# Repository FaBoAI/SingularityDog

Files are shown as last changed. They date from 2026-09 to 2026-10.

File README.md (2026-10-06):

# SingularityDog

**GPT-6 Astraが、3D CADの設計・強化学習・評価・改善を進めるロボット犬プロジェクト。**

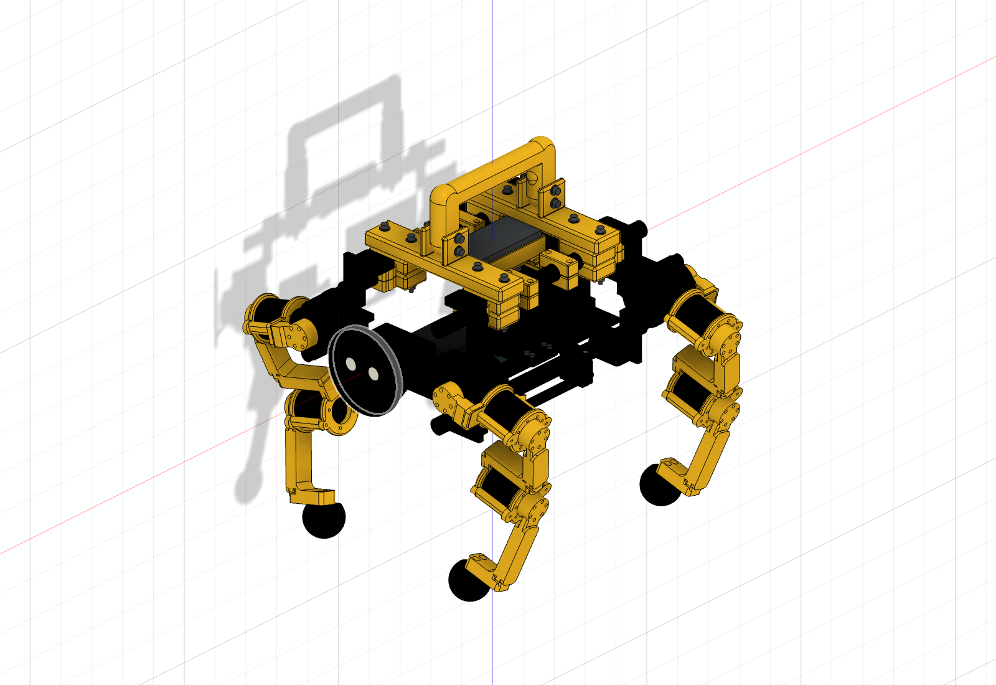
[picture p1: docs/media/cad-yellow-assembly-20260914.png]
SingularityDogの黄色・黒のCAD全体像。黄色の脚・取手、黒いBodyと顔を備えた2026年9月14日の全体CAD更新版


*黄色の脚・取手と黒いBody・顔を反映したCAD全体像（2026-09-14の全体更新版）。その後の共通底板・顔固定・左右連結部・足先の改訂は、[最新STL部材一覧](docs/stl-parts.md)で確認できます。*

**[BOM・部品表](docs/bom.md)** · **[色別STL・ダウンロード](docs/stl-parts.md)** · [動画で見る進捗](#動画で見る進捗) · [実機向けソフトウェア開発](#実機向けソフトウェア開発) · [実機Deploy](#実機deployの状況) · [現在の課題](#現在の課題) · [ハードウェアライセンス](#ハードウェアライセンス)

## GPT-6 Astraと、実物を作りながら開発する

SingularityDogは、**GPT-6 Astraを開発エージェントに据え、人と一緒にロボット犬を作る**FaBoのプロジェクトです。GPT-6 Astraが機構・固定具の設計変更、STLの準備、制御・学習コード、Isaac Labでの実験と結果整理を進めます。人は目標を決め、部品の採寸・調達・印刷・組立を行い、割れや嵌合などの現物情報を返します。

**設計 → シミュレーション・学習 → 動画と数値で評価 → 印刷・現物合わせ → 実機計測 → 改善**を繰り返します。うまくいかなかった試行も記録し、次の設計と学習に反映する開発記録です。

シミュレーションは**第37回まで評価済み**です。実機ではRS05全12軸を公式FW 0.5.0.13へ更新し、前後2系統のCANで保持・停止を確認しています。前進の最終目標は40cm/sです。

## 実機向けソフトウェア開発

**[10月6日の総括・残件の○△×表](docs/work-summary-20261006.md)**。C複製＋FK最適化で無出力の定常1,000周期を20ms以内に収めました。新設定の実Type1出力、荷重支持、自立、歩行は残件です。今日の修正ソース・テスト・IMU候補・実出力の先行履歴をまとめています。

**[10月6日夜：20ms超過の原因調査と修正](docs/20ms-cause-investigation-20261006.md)**。**0.90ms送信間隔・20ms制御周期を維持し、無出力の定常1,000周期を20ms以内に収めました。** C++待機の修正、関節目標のC++化＋FK再利用、snapshotのC複製を組み合わせたr49で、取得・実推論・12軸STOP代理返信・後処理を500周期×2回測定。最大19.856942／19.788521ms、定常超過・周期スキップ0で、原通信と設定復元も独立確認しました。初回20.066911／20.045173msは許容された初回として別記録。出力98値の新C++変換も保存入力で短縮を確認しましたが、今回の周期には未統合です。**新設定の実Type1出力・荷重・立位・歩行は残件**です。[本日の記録とToDo](docs/today-validation-20261006.md)・[実出力の履歴](docs/corrected-output-validation-20261006.md)。

**[10月5日の総括・残件の○△×表](docs/work-summary-20261005.md)**。静止速度・原点精度の解析、校正入力と保存処理の修正、気泡式水準器1台用の簡単な音声手順r2も含めて整理しました。ID4・5・10の相対方向候補は確認済み、絶対原点とIMUの正式校正、現設定の学習目標実送信・荷重立位・歩行は残件です。

**2026年10月5日：gyro偏差を選択したr3の無出力実モデル診断で、定常500周期を2回とも20ms以内に収めました。** 最大19.355386ms／19.253048ms・処理時間超過0・返信欠落0。gyro候補は未承認の仮定として入力へ適用し、加速度はrawのままです。開始間隔最大20.073992ms／20.005319msの厳密20ms未達と、短い5周期の初回20.014758msも残します。一括静止比較は速度判定でBLOCKED、全12軸の最終原点・IMU絶対校正は未確定、新設定の学習目標送信・荷重立位・歩行は未実施です。[今日の記録・手順](docs/today-validation-20261005.md)・[r1〜r3実測集計](evidence/validation-live-timing-20261005.json)。今週10月5〜11日に、正式荷重設定→部分荷重→自立→短距離歩行を目指します。[修正・○△×表・日別計画](docs/walking-week-20261005.md)。`r`／`R`番号は各ツール・試験内の改訂番号で、学習評価回数とは別です。

| 日付（2026年） | 版・作業記録 | 成果・状況 |
|---|---|---|
| 9月20日 | [診断 r2・r4](docs/hardware-bringup-20260920.md) | 12軸の位置・速度・電流・電圧とIMUを取得。60秒診断でCANタイムアウト0回。 |
| 9月21日 | [関節試験・推論環境](docs/hardware-results-20260921.md) | 支持台上で右前脚の動作・停止を確認。12軸の逐次取得は中央値81.20ms。 |
| 9月22日 | [FW照会・校正準備](docs/hardware-results-20260922.md) | 全12台の版数を照会し、設定読取り失敗を切り分け。試験前の設定確認を一括化。 |
| 9月23日 | [前後2系統CAN・交換後の試験](docs/hardware-results-20260923.md) | USB2CANを前脚・後脚に分割。交換後の脚別動作・停止と4脚のL字基準を記録。 |
| 9月24日 | [保持 r1〜r6](docs/hardware-results-20260924.md)・[20ms化の方針](docs/control-20ms-strategy-20260924.md) | 右後脚の追従とゲインを比較。位置・速度の複合返信、並列取得・送信の改善方針を整理。 |
| 9月25日 | [FW更新・実機結果](docs/2026-09-25-26-hardware-status.md#9月25日)・[C++化 r10／r8](docs/hardware-native-host-processing-20260925.md) | 全12軸をFW 0.5.0.13へ更新。取得→実推論→最終ホスト送信は3回中最良19.785ms、最大20.136ms。連続20msは未達。 |
| 9月26日 | [音声案内・12軸保持](docs/2026-09-25-26-hardware-status.md#9月26日)・[4軸同時試験](docs/role-thigh-mirrored-20260926.md) | 「テスト開始します」の発話と12軸保持・STOPを確認。前脚付け根の10°軌道は未完了。 |
| 9月27日 | [並列取得・無出力推論 r3・r4](docs/learned-policy-deploy-status-20260927.md) | 前後CAN・IMUを並列化し、単発の実推論に成功。r4はCAN取得中央値22.183msで、20ms未達。 |
| 9月27日夜 | [翌日の一括検証キット](docs/overnight-validation-20260927.md) | 360°ずれの補正、IMU校正、C++送受信・推論を統合。保存通信492件の一致と模擬20周期を確認。 |
| 9月28日 | [速度改善 r6〜r13](docs/hardware-native-cycle-20260928.md) | 複合返信、スレッド事前起動、コピー削減、ログ後処理化。r13は無出力500周期の全工程最大21.640ms、16回超過。 |
| 9月28日 | [CPU・推論比較 r14〜r17・R20〜R22](docs/latency-alternatives-20260928.md) | Super Modeと推論の準備手順を改善。**R22で無出力500周期すべて20ms以内（全工程最大19.695ms）を達成。** |
| 9月28日 | [実出力 V2／V3](docs/policy-output-validation-20260928.md)・[立位〜低速歩行ツール](docs/ground-trials-20260928.md) | 滑らかな開始・停止、C++送受信、関節監視を実装。V3は周期内の要求を28→26へ削減。 |
| 9月28日夜 | [角度・IMU照合、指令断確認 r4](docs/walking-residuals-20260929.md)・[40V再投入5回](docs/power-cycle-repeat-20260928.md) | 水準器で4脚L字とIMU水平を記録。ゼロゲインの指令断保護・終了STOPを12軸で確認。加速度ノルム約9%の偏差は残る。 |
| 9月28日夜 | [⑤ 最終入力の無出力診断](evidence/final-input-diagnostic-20260928.json) | **取得→実推論→STOP返信・後処理まで、初回1＋定常500周期すべて20ms以内を達成。全工程最大19.555ms、超過0回。** |
| 9月29日未明 | [⑥ 箱支持の実出力試行](evidence/supported-policy-attempt-20260928.json) | 開始保持2周期後、指令計算間隔の上限で中断。学習目標は未送信。終了STOPは10軸確認・2軸未確認となり、40V Off・現物異常なしを確認。 |
| 9月29日未明 | [朝の再開手順・修正版](docs/morning-restart-20260929.md) | 指令間隔の記録とSTOP返信処理を修正し、CPU配置の比較設定を追加。**2,303件成功・5件スキップ**。修正版の実機再試験は未実施。 |
| 9月29日 | [実出力と20ms比較](docs/20ms-fast-voltage-benchmark-20260929.md)・[推論のC++候補](docs/20ms-model-hotpath-20260929.md) | 箱支持で学習目標を混ぜる2秒試験を95周期完走・全軸STOP。数値計算スレッドを起動時に制限した無駆動診断は、初回を除く**3回×500周期で20ms超過0回**（各回最大19.392／19.303／19.910ms）。同じCPU4で追加の定常500周期も最大19.663ms・超過0。新設定の実出力は初回ゼロゲイン周期で返信が欠け、学習目標送信前に中断。 |
| 9月29日 | [STOP再送と返信欠落の切り分け](docs/stop-retry-20260929.md) | ゼロゲインのType1比較は29周期完了後、30周期目のID4返信欠落で中断。40V Off・現物異常なし。STOP最大3回・合計500msの再送を実装し、実機での効果は未計測。 |
| 9月29日 | [STOP再送版の箱支持実出力 r1](evidence/supported-policy-stopretry-20260929.json) | 充電後、ゼロゲイン88周期と学習目標送信97周期を完走。学習目標側は全工程最大**19.575ms・20ms超過0回・全12軸STOP**。モデル混合率0.5%、最大1°の限定試験。再送は発動せず、返信欠落時の回復効果と長時間安定性は未確認。 |
| 9月29日 | [12cm支持・5秒試験 r1〜r6](docs/ground-support-rehearsal-20260929.md)・[集計](evidence/supported-policy-box120-20260929.json) | STOP初回250ms・再送最大500ms・合計1秒、有効化返信30ms、終了ランプの丸め誤差を修正。r6は32周期（学習目標12周期）後にID12返信欠落で中断。完了周期最大19.439ms。40V Off・現物異常なしを確認。5秒完走と通信欠落の解消は未達。 |
| 9月29日 | [CAN/USB欠落調査・skip試作](docs/can-usb-loss-investigation-20260929.md) | 返信全体の未着と末尾2バイトの遅着を分類。xHCIの受動監視ツールを追加。最大1周期の受信待ちを模擬検証し、Mac74件・JetsonのC++ socket3件成功。実出力のskipは未適用、欠落の物理的な発生箇所は未確定。 |
| 9月29日 | [実機Type17・USB双方向記録](docs/can-usb-loss-investigation-20260929.md)・[集計](evidence/can-usb-type17-live-20260929.json) | 箱支持・無指令で500周期を完走。xHCIは前後両CH341の送受信URBを損失なく記録。ID9の40V再投入後の約1回転枝差を診断用に照合。Type1欠落の発生箇所は未確定。 |
| 9月29日 | [ID9角度照合・推論＋STOP代理100周期](docs/can-usb-loss-investigation-20260929.md)・[集計](evidence/can-stopproxy-diagnostic-20260929-r3.json) | 現起動12軸の無出力読取りを診断用プロファイルと照合し、100周期を完走・全12軸STOP返信を確認。標準モデル経路では推論区間中央値28.729ms、全工程中央値46.191ms。高速C++モデルの指定漏れを防ぐCLIスイッチを追加し、同条件の再比較を準備。 |
| 9月29日 | [高速C++モデルの無出力再計測](docs/can-usb-loss-investigation-20260929.md)・[集計](evidence/can-stopproxy-fastscalar-20260929-r5.json) | CPU周波数を計測中だけ固定し自動復元。初回1＋定常500周期を完走し、定常の取得→実推論→12軸STOP返信・後処理は中央値18.831ms、最大19.482ms、20ms超過0回。Type1指令とモーター有効化はゼロ。実出力と厳密な開始間隔20ms以内は未確認。 |
| 9月29日 | [Type1欠落の密度・有効化比較](docs/can-usb-loss-investigation-20260929.md)・[集計](evidence/can-usb-loss-followup-20260929.json) | 実出力r7は43周期目のID4返信が欠落し、物理40V Off。脱力中の26要求r17は50周期、有効化ゼロゲインの同密度r19も50周期を完走し、いずれも全軸STOP。r19は前後各710要求／返信、USB送受信各12,070Bが一致。**欠落原因は未特定**で、長時間の学習目標出力は未承認。 |
| 9月29日 | [native通信密度比較 r20〜r29](docs/can-usb-loss-investigation-20260929.md)・[集計](evidence/can-usb-loss-followup-20260929.json) | CPU・待機最適化後の0.8msは50周期すべて20ms以内だが、500周期試行の19周期目で返信欠落。USB受信側でも17B不足を確認。**1.0ms間隔ではゼロゲイン500周期を欠落なし・全12軸STOPで完走**。最大20.415ms、20ms超過16周期。0.9msでは186周期完了・187周期目にID4速度0.506rad/sで停止、返信欠落・時間超過はなく最大19.427ms、全軸STOP。学習目標・荷重試験の成功ではない。 |
| 9月29日 | [新起動の静止読取り・返信比較 r30・r31](docs/stationary-readonly-check-20260929.md) | r30は全12軸・10秒・3012要求を完了し、角度幅最大0.02552°。r31は36 STOP返信すべてmode0・fault0、ID4・6は各3回一致。全体は31一致・5判定保留。有効化・学習目標送信なし。実出力、最終角度承認、20ms達成の判定には用いない。 |
| 9月29日 | [0.9msの推論・STOP診断 r33〜r36](docs/control-loop-gil-optimization-20260929.md) | Python切替100µsと電圧通信準備後の通知で、r36は初回20.175ms・定常500周期すべて20ms以内（最大19.940ms）、返信欠落なし。修正版の通信断保護も12軸合格。過去起動の実測として保存。充電後の現起動の結果は次行。 |
| 9月29日 | [満充電・STOP解析短縮 r38〜r43](docs/control-loop-gil-optimization-20260929.md) | 現電源の通信断保護は全12軸合格。r43は501周期返信欠落なし、定常499/500周期が20ms以内（中央値19.273ms）。残る1周期は返信後処理で21.100msとなり、支持付き実出力の開始条件は未達。学習目標は未送信。 |
| 9月29日 | [C++一括エンコード・支持付き実出力 r46〜r49](docs/control-loop-gil-optimization-20260929.md#c一括エンコードで支持付き実出力を完走r48r49)・[集計](evidence/control-loop-gil-20260929.json) | r48は入力年齢20.048msで中断・学習未送信・全軸STOP。C++一括エンコーダーを選んだr49は**2秒枠・92周期を正常終了し、全工程最大19.959ms・超過0回・全12軸STOP・現物異常なし**。学習混合48周期、上限0.5%・最大1°。開始間隔最大20.0226ms。10秒・荷重立位・歩行は未実施。 |
| 9月29日 | [10秒版の初回試行 r50](docs/control-loop-gil-optimization-20260929.md#10秒版の初回試行r50途中停止)・[集計](evidence/control-loop-gil-20260929.json) | 開始2周期が20.110677／20.062804msとなり、返信後の連続超過で中断。学習混合率0・学習目標未送信、全12軸STOP・現物異常なし。**10秒完走は未達**で、開始直後の処理を調査中。r49の2秒成功とは別に保存。 |
| 9月29日 | [初回猶予の2秒再確認 r51](docs/control-loop-gil-optimization-20260929.md#初回猶予を明示した2秒再確認r51鮮度で中断)・[集計](evidence/control-loop-gil-20260929.json) | 最初の周期が20.309195ms、入力年齢20.093303msで中断。鮮度条件を満たさず初回猶予は未使用。学習目標未送信、全12軸STOP・現物異常なし。開始処理・返信解析の短縮が残る。 |
| 9月29日 | [主制御の返信解析短縮・2秒再完走 r52・r53](docs/control-loop-gil-optimization-20260929.md#固定長返信解析で2秒を再完走r52r53)・[集計](evidence/control-loop-gil-20260929.json) | r52は54周期後に指令計算間隔21.364msで中断・全軸STOP。主制御解析を短縮したr53は**92周期正常終了、初回20.138msの猶予1回、定常最大19.887ms・超過0回、全12軸STOP・現物異常なし**。学習混合48周期・モデル68回。最大1°／混合0.5%の箱支持試験で、次は同じソースの10秒確認。 |
| 9月29日 | [同一ソースの10秒完走 r54](docs/control-loop-gil-optimization-20260929.md#同一ソースの10秒枠を完走r54)・[集計](evidence/control-loop-gil-20260929.json) | **494周期で正常終了、モデル468回・学習混合448周期・全12軸STOP・現物異常なし**。全工程中央値19.362ms、単発超過1回・最大20.190ms。最終返信は全周期20ms以内。最大1°／混合0.5%の箱支持試験。次は箱を残した荷重用保持の確認で、支持減・自立・歩行は未実施。 |
| 9月29日 | [箱支持Kp12・3秒保持 r55](docs/control-loop-gil-optimization-20260929.md#箱を残したkp12の3秒保持r55)・[集計](evidence/control-loop-gil-20260929.json) | **138周期で正常終了、全工程最大19.624ms・超過0回・全12軸STOP・現物異常なし**。Kp12/Kd0.15へ1秒かけて上げ、現在位置を保持。周期中のモデル呼出し・学習目標は0。箱を残した試験であり、荷重移行・自立・歩行の証明ではない。 |
| 9月29日 | [固定受け付き30秒保持の試行 r56f・r57](docs/fixed-catch-hold-20260929.md) | r56fは姿勢変更後の開始角不一致で駆動前停止。r57は高い箱を抜いた後、約6.1秒でIMU値により中断し全12軸STOP。実測トルクは最大約0.11 Nmで、脚の荷重支持は確認できなかった。次は箱を残して小変位の脚伸展と荷重を測る。 |
| 9月29日 | [学習目標0.5%→1%・Kp6の支持付き出力 r63・r64](docs/fixed-catch-hold-20260929.md#同日夜のkp6学習目標1段階試験)・[集計](evidence/supported-gain-contact-20260929.json) | r63は2秒枠・95周期、r64は3秒枠・143周期で正常終了。両方とも定常20ms超過0・全12軸STOP・現物異常なし。r64の最大実測トルク約0.065Nm、最大実移動約0.066°で、荷重支持の証明ではない。 |
| 9月29日 | [4足接触確認と0.25mm往復経路 r65](docs/fixed-catch-hold-20260929.md#紙による4足接地確認後の読取りr65) | 4足で紙が軽く挟まることを操作者が確認。12軸の静止角を無駆動で取得し、5秒往復経路を数値検査。微小IKの収束誤差を修正。専用実行処理への接続・異常時STOP検証・新電源での照合は残件で、実機への経路送信は未実施。 |
| 9月30日 | [5秒の伸展・復帰処理](docs/supported-preload-runtime-20260930.md)・[追加課題の修正](docs/additional-fixes-20260930.md)・[ToDoと時間](docs/walking-plan-20260930.md) | 専用実行モード、角度枝・復帰・STOPを実装。追加監査で古いSTOPの混入、終了・速度判定、旧診断の流用、送信角の量子化、キット一覧の重複を修正。Mac上の擬似通信で検証し、現電源での診断・実機送信・荷重移行は残件。 |
| 9月30日 | [全体監査・総合課題表](docs/system-readiness-20260930.md)・[モデル規模とESP32](docs/model-footprint-esp32-20260930.md) | 取消例外とSTOP結果保存、端末出力の詰まり、遅いEnter、IMU二重補正、数値変換、子プロセス中止、キット・証拠の整合性を修正。新ソースのJetson実時間と実駆動は未計測。 |
| 10月2日 | [実機向けソフトウェア・試験履歴 r1〜r18](docs/resume-20261002.md#再開初期からr18までの状況履歴) | 360°の枝選択、軸別の開始確認、音声説明、人の支持付き保持を実装。複数起動で箱支持の0.5%・最大1°の2秒／10秒とKp6の短時間試験が成功。各結果は起動・電源・姿勢ごとに保存。荷重支持・起立・歩行は未検証。 |
| 10月2日 | [CAN・IMU一括待機 r19](docs/resume-20261002.md#一括待機版の配置と現起動の無出力再比較r19) | 関連168件が合格。箱上2秒／10秒を96／496周期完走し、全工程最大19.985／19.918ms・20ms超過0・全12軸STOPを確認。旧起動の限定成功であり、遅延外れ値の根本原因は未確定。 |
| 10月2日（履歴） | [課題・修正・残件](docs/resume-20261002.md#コミット時点の課題と修正)・[電圧合流待ち r20〜r22](docs/resume-20261002.md#電圧の合流待ちを限定的に短縮する版r21) | 電圧待機の最適化を実装し、実出力／無出力の各114テストが合格。新569ファイルKITを配置。再起動後の通信断診断はID10の有効化返信欠落で中断し、全軸STOPの確認は不成立。この時点で新版501周期・2秒／10秒・10%混合は未実施。 |
| 10月3日（ソフト） | [修正・○△×表・歩行計画](docs/walking-week-20261005.md)・[検証集計](evidence/walking-preparation-20261003.json) | 再STOPの曖昧さ保持、地上判定・端末・原票・生記録保存先を修正。取得合流待ちを最大200µs刻みのC++待機へ変更し、欠落解析ツールを追加。新版のJetson配置・実出力・荷重試験は未実施。 |
| 10月5日 r1 | [診断・校正手順](docs/today-validation-20261005.md#10月5日r1の実測結果)・[準備集計](evidence/validation-preparation-20261005.json) | 576ファイル照合・Jetsonビルド・モデルABI照合が成功。独立した無出力定常500周期2回で最大19.814799／19.705298ms・超過0。再測定初回20.046395msと厳密開始間隔未達、一括静止比較BLOCKEDを履歴として保存。 |
| 10月5日 r2 | [通知順序・100µs切替の再測定](docs/today-validation-20261005.md#r2通知順序とスレッド切替を揃えた再測定)・[実測集計](evidence/validation-live-timing-20261005.json)・[角度の不足項目](docs/angle-final-review-20261005.md) | 577ファイルを照合。**無出力の定常500周期2回で、全工程最大19.249016／19.363259ms・20ms超過0・返信欠落0**。別の12軸ゼロゲイン指令断確認も全軸STOPまで成功。再測定初回20.037160ms、厳密開始間隔未達、最終角度・IMU・実モデル目標送信の残件は維持。 |
| 10月5日 IMU A/B | [追加静止計測](docs/today-validation-20261005.md#40v-offの静止imu-ab追加)・[実測集計](evidence/validation-live-timing-20261005.json) | 40V Offで各30秒を収録・設定復元。独立Bのgyro残差最大0.004140rad/s。両収録の実静止・取付と姿勢未変更を操作者が確認し、gyro候補を新規保存。その後の診断入力選択は別行へ記載。加速度ノルム+8.74%／+8.79%は未解消。 |
| 10月5日 r3（配置時点） | [一括入口の配置](docs/today-validation-20261005.md#r3次回用の一括入口を配置)・[集計](evidence/validation-live-timing-20261005.json) | 100µs指定と子の前後でのwrapper確認を一括入口へ反映。61件・独立レビュー合格。Jetsonで577ファイルSHA・モデルABI・PLANを確認した準備の履歴。後の実測は次のr3行へ分ける。 |
| 10月5日 gyro診断設定 | [偏差の選択・入力変換](docs/today-validation-20261005.md#静止gyro偏差を診断入力へ設定)・[集計](evidence/validation-live-timing-20261005.json) | r3の診断入力へgyro偏差を選択。保存B＋Cの実入力変換41,522件・最大差0。C平均ノルム0.023002→0.000900rad/s、全サンプル最大0.004778rad/s。Cの実静止は未確認、候補の最終runtime承認は未達。後の実モデル推論は次行へ分ける。 |
| 10月5日 r3（gyro選択付き実測） | [無出力モデル診断](docs/today-validation-20261005.md#r3gyro選択付きの無出力モデル診断)・[実測集計](evidence/validation-live-timing-20261005.json) | 未承認gyro仮定＋raw加速度で5／50／501周期2回の実推論・STOP代理を完走。**定常500周期2回の最大19.355386／19.253048ms・超過0・欠落0**。開始間隔最大20.073992／20.005319msと短い5周期の初回超過を保持。一括比較はID6／9の速度端点でBLOCKED、full未実行、新設定の学習目標送信も未実施。 |
| 10月5日 方向・静止速度 | [関節レビュー](docs/angle-final-review-20261005.md)・[追加解析](docs/stationary-velocity-origin-remediation-20261005.md) | ID4・5・10の相対方向と復帰を照合。535点の位置・速度を解析し、復号誤りは見つからず。静止速度の原因と絶対原点精度は未確定。 |
| 10月5日 水準器 r1／r2 | [簡単な目視・音声手順](docs/stationary-velocity-origin-remediation-20261005.md#追加した実測の記録ツール)・[総括と残件](docs/work-summary-20261005.md) | r1の数値入力での中止を保存。r2は水準器1台・3回の言葉入力へ修正し、配置・PLAN照合まで完了。新しい目視観察は未収録、角度精度はnullを維持。 |
| 10月6日 r1・撮影／IMU追加 | [本日のToDo・修正・開始結果](docs/today-validation-20261006.md)・[画像とPVP](evidence/stationary-optical-capture-20261006.json)・[IMU別収録](evidence/imu-holdout-20261006.json)・[最終ソース検査](evidence/validation-followup-20261006.json) | 599ファイル配置、12軸84/84返信、C++通信・モデルのファイルビルド、水準器3観察を完了。ID5の画像425枚・PVP50組は欠落0。IMU2,909点は固定した昨日のgyro候補で残差最大0.004824rad/s、設定復元・独立監査成功。有限撮影・校正メモ・画像時刻・gyro入力SHAを修正し、755件中743合格・12件スキップ。この時点では速度の原因、ID3・6・9の枝、原点・IMU絶対精度が残り、今日の20ms・実出力は未測定。 |
| 10月6日 脚調整後 r1・r2 | [角度・20ms再比較・補正モデル比較](docs/post-adjust-diagnostic-20261006.md)・[集計](evidence/post-adjust-diagnostic-20261006.json) | 全12軸の数値的な枝を一意に選択。性能設定を揃えた**無出力501周期は最大19.906224ms、超過・返信欠落0**。IMU補正前後×h0/1の保存推論は各400回完走。この時点では新補正の実機適用・荷重支持・歩行は残件。 |
| 10月6日 新IMU入力仮説・実出力 r1／r2 | [501診断・箱支持2秒](docs/corrected-output-validation-20261006.md)・[集計](evidence/corrected-output-validation-20261006.json) | r1は44周期後に間隔監視で中止。timer処理修正後のr2は**95周期・モデル68回、最大19.995265ms・処理期限超過0・正常ramp終了・全12軸STOP**で完走し、原通信独立監査と現物異常なしの確認を保存。正式IMU校正と絶対角度精度は未承認・未知。荷重支持未実施。後続10秒r1は145周期で年齢監視により中止し、全12軸STOP。中止原本の独立監査は通過、10秒完走は未達。 |
| 10月6日 返信待ち修正後の診断 r4 | [新補正の実測と開始条件](docs/corrected-output-validation-20261006.md)・[集計](evidence/corrected-output-validation-20261006.json) | 無出力501周期の記録は完了。初回19.917305ms、定常500周期は最大20.945170ms・処理期限超過1回で実出力開始条件は未達。予定終了期限超過2回、全12軸STOPを記録。K6実出力は未実施、診断側の待機修正は次行へ別記録。 |
| 10月6日 診断合流待ち修正 r5 | [新補正の実測と開始条件](docs/corrected-output-validation-20261006.md)・[集計](evidence/corrected-output-validation-20261006.json) | K7の501診断は初回proxy出力合流待ちの20ms期限で中止し、完了0周期。有効化・学習目標送信なし、実出力開始条件未達。この時点ではK8の転送前にSSH接続を失い、未配置。再接続後のR6は次行へ別記録。 |
| 10月6日 K8再接続後の診断 r6 | [新補正の実測と開始条件](docs/corrected-output-validation-20261006.md)・[集計](evidence/corrected-output-validation-20261006.json) | **無出力501周期を完走、初回20.386889msの既存許容、定常500周期最大19.814066ms・処理と予定終了期限超過0・独立原本監査PASS**。開始間隔257／499区間は厳密20ms超、最大20.080860ms。この最初のr6では新2秒PLANを準備。後続再計測の失敗は次行へ別記録。 |
| 10月6日 同一K8の診断 r6-repeat1 | [新補正の再現確認](docs/corrected-output-validation-20261006.md)・[集計](evidence/corrected-output-validation-20261006.json) | 501周期の記録は完了したが、定常cycle180の全工程20.208016ms・入力年齢20.001097msで時刻条件未達。処理と予定終了期限超過は各1回。新実出力は立会いと時刻条件の再確認待ち、profileはPLANのみ。 |
| 10月6日 新bootのR8／R9・追加解析 | [4回の501比較とboot検査A/B](docs/corrected-output-validation-20261006.md)・[集計](evidence/corrected-output-validation-20261006.json) | 新bootの無出力501周期×4回を記録し、定常処理超過は3回が0、R8既定経路で1件。各原通信監査PASS、診断専用で実出力の開始資格には不適格。ファイル／CPU専用A/BとGC遅延版は各300,000回を検算し、nativeの一貫した尾部改善は未確認。新しい有効化・学習目標送信なし。 |
| 10月6日 無出力20msの再試験 | [電圧下限による中止](docs/corrected-output-validation-20261006.md)・[集計](evidence/corrected-output-validation-20261006.json) | 後系統最低34.983932Vが35V下限を下回り、代理STOP出力前に中止・完了0周期。有効化・学習目標送信なし、設定復元を記録。この試験の20ms達成は判定不可、当時は充電・交換の確認待ち。 |
| 10月6日 充電・交換後の無出力501再試験 | [最新の無出力測定](docs/corrected-output-validation-20261006.md)・[集計](evidence/corrected-output-validation-20261006.json) | 501周期完了、定常最大19.829227ms・処理／予定完了超過0・skip0、独立原本監査PASS。初回20.419991msと開始間隔最大20.006574msは分ける。有効化・学習目標なし、診断専用で実出力資格へ転用不可。 |
| 10月6日 canonical K11・新sourceの2秒試行 | [新補正の診断・実出力](docs/corrected-output-validation-20261006.md)・[集計](evidence/corrected-output-validation-20261006.json) | 630member・凍結source589filesの独立照合とprepared publication統合を完了。scoped診断は173周期後中止、repeat501は定常処理超過0・予定期限超過1。実出力2秒は初回sample-ageで中止、有効化・開始時の減衰指令あり、学習目標未送信・全12軸最終STOP。新sourceの2秒成功・10秒・荷重は未達。 |
| 10月6日 K12・返信後input-age V2準備 | [新sourceの無出力R14](docs/corrected-output-validation-20261006.md)・[集計](evidence/corrected-output-validation-20261006.json) | 634member・凍結source593filesを独立照合、targetファイル専用175件PASS。501周期・定常最大19.759694ms・処理／予定期限超過0、転送中断後の全量回収・独立原本監査PASS。この診断時点ではK12の新実出力は未実施で、後続結果は次行。 |
| 10月6日 K12 V2・箱支持2秒実出力 | [最新の有限2秒試験](docs/corrected-output-validation-20261006.md)・[集計](evidence/corrected-output-validation-20261006.json) | **95保存周期・モデル68回で正常終了、学習目標送信・全12軸最終STOP・独立原本監査PASS**。初回20.417671ms／入力年齢20.075805msは明示許容を1回、定常94周期最大19.915352ms・超過0。最大指令0.255462°。K12の10秒・荷重は未実施。 |
| 10月6日 K12後の期間延長・電源／姿勢更新 | [中止と再診断の経過](docs/corrected-output-validation-20261006.md)・[集計](evidence/corrected-output-validation-20261006.json) | 10秒はID8有効化返信欠落で0周期、STOP資格11／12軸のため40V Off。再投入後R16無出力501は定常最大19.860461ms・処理超過0。新電源2秒はID7開始角度の候補0件で駆動前中止・全12軸STOP。後から電源再操作・手動移動を申告、現姿勢R17も501周期・定常最大19.867431ms・処理超過0で原本監査PASS。10秒・20秒実出力未達 |
| 10月6日 再開準備・保存ログの読込み修正 | [再開時の条件](docs/today-validation-20261006.md)・[ログ変換ツール](tools/compact_diagnostic_evidence.py) | 電源・姿勢変更後の2秒→10秒→20秒の入口を準備。ログ変換24件、入口の合成PLAN13件のテストを通過。R17の全値・時刻・bytesを保持したままrecordsを16MiB以内へ保存。Macで照合済み、Jetson配置と実出力は未実施 |
| 10月6日 Jetson再起動後R18・保存ログ変換 | [最新の無出力検証](docs/corrected-output-validation-20261006.md)・[集計](evidence/corrected-output-validation-20261006.json) | 501周期・初回20.048744ms、定常最大19.835106ms・処理超過0。原通信・実float32入力と復元を独立照合。Jetson上で全値・時刻を保持した別records16,666,408bytesへ変換済み。現在の±3°経路を直接確認、再起動後zeroと実出力は未実施 |
| 10月6日夜 R19〜R30 | [原因調査・C++待機修正・モデル比較](docs/20ms-cause-investigation-20261006.md) | 送信間隔・CPU配置の成功と再失敗を原本監査。診断／実出力C++の相対待機を修正、偽syscall28件と関連target188件PASS。保存501＋合成240周期のモデル比較は出力・内部状態一致、forward中央値の差約0.063ms。新通信の実機比較は後続R31以降に記録。現起動の正ゲイン実出力は未実施。 |
| 10月6日夜 R31〜R37 | [0.90ms再比較・待機修正・C++候補](docs/20ms-cause-investigation-20261006.md)・[集計](evidence/20ms-cause-investigation-20261006.json) | 新C++待機は216件のtarget・pipe ABI確認、新ソースは233件PASS。R34は141周期、R37は33周期完了後に期限超過。原返信・判定時刻・復元を照合。連続20msは未達。関節目標C++＋FK再利用は保存入力で一致、中央値1.680→1.586ms。全工程へは未適用。 |
| 10月6日夜 r38〜r47 | [C++候補の実測と読み込み修正](docs/20ms-cause-investigation-20261006.md#r47保存入力で速かった候補を無出力診断へ接続)・[集計](evidence/20ms-cause-investigation-20261006.json) | 完了通知の5周期比較を2回実施。永続C++ workerはLinux模擬37件PASSで実通信未接続。98値変換は実Jetsonで約0.020ms遅く、不採用。FK候補は読み込み修正63件PASS、実モデル・ライブラリのファイル検証成功。無出力5周期試行は後側34.808Vで代理送信前に中止・完了0、501周期は未実施。CPU等の復元と原本監査を確認。 |
| 10月6日夜 r48〜r49 | [C複製・C++最適化と実測](docs/20ms-cause-investigation-20261006.md#r49c複製とfk最適化で無出力の定常20msを達成)・[集計](evidence/20ms-cause-investigation-20261006.json) | **無出力の定常20ms以内を達成：500周期×2、最大19.857／19.789ms・超過0。** 0.90msと20ms期限を維持し、取得・実推論・12軸STOP代理返信・後処理を原通信から独立確認。初回20.067／20.045msは別記録。ID9調整後の12軸モデル範囲と設定復元も確認。新設定の実Type1出力・荷重支持・歩行は残件。 |

10月6日の先行解析：[傾斜を許容するIMU補正と独立6姿勢の検算](docs/imu-six-face-results-20261006.md)・[集計](evidence/imu-six-face-calibration-20261006.json)。12収録・11,650点を回収し、独立6姿勢のノルムRMS誤差は最大0.43216%。[姿勢調整後の20ms・モデル比較](docs/post-adjust-diagnostic-20261006.md)ではraw入力の無出力501周期と4条件の保存推論を確認しました。その後、[箱支持限定の新入力仮説](docs/corrected-output-validation-20261006.md)として実入力へ選択し、2秒実出力を完走。正式IMU校正や絶対姿勢精度の承認とは分けます。

r3の5／50／501周期2回、全1,057周期は独立した原記録監査も合格し、gyro実入力・float32観測・全軸STOP返信・固定577ファイルを照合しました。最終校正や実出力の承認にはしません。[監査の範囲とSHA](evidence/validation-live-timing-20261005.json)。

表の「全工程20ms以内」は、無出力診断では取得・実推論・STOP代理送信・返信・後処理を含む処理時間、実出力と明記した行では実指令・返信を含む記録周期の処理時間です。周期開始間隔とは別に計測し、初回1周期と観測済みの開始ジッターは[採用条件](docs/accepted-angle-timing-policy-20260928.md)に従います。

[10月5〜11日の歩行計画・最新課題](docs/walking-week-20261005.md) · [総合課題表・修正](docs/system-readiness-20260930.md) · [9月30日のToDo・スケジュール](docs/walking-plan-20260930.md) · [朝の再開手順](docs/morning-restart-20260929.md) · [一括試験の実施方法](docs/today-test-plan-20260928.md)

## 機体とBOM

| 構成 | 現在の設計 |
|---|---|
| 駆動 | 4脚×3軸、RobStride RS05×12。実機も全個体RS05と操作者が確認 |
| フレーム・外装 | カーボンポールとPLA印刷部品。脚・取手・上部は黄色、Body・顔枠・足先は黒 |
| 計算・姿勢計測 | Jetson Orin Nano、RobStride USB2CAN（CH340）×2（前脚／後脚）、GY-ICM20948V2（I2C） |
| 電源 | Makita 40V 2.5Ahとモバイルバッテリー。MakitaとJetsonは共通底板へ固定 |
| 顔 | φ96mmディスプレイ＋ESP32-S3。前面リングを4本のネジで固定 |

**[BOM全件：数量・寸法・重量・未確定項目](docs/bom.md)**<br>
**[STL一覧：黄色44個・黒45個の候補構成](docs/stl-parts.md)**

STLは個別に取得できます。89個は1台の候補構成数で、これから印刷する残数ではありません。現在の選定は、PLA補強、左右連結部の補強、K1 Max用の共通底板、顔の前面固定、外側でナットをセットできる足先r3を含みます。実際に装着した版と、荷重・嵌合の確認結果はこれから記録します。

## 動画で見る進捗

**第1・2・3・10・20・30回**をたどります。プレビューをクリックすると動画ファイルを開けます。第1・2回は公開録画がなく、第3回は計測チャート、それ以降の掲載映像はシミュレーション録画です。

| 第1回 — まず1本ずつ足を上げる | 第2回 — 周期運動へ進む |
|---|---|
| 92秒・31区間の荷重移動を実行し、4脚それぞれ約20mmの足上げを保持。<br>**公開動画なし** · [記録](evidence/learning-history.json) | 周期参照を3条件で比較。全脚が15mm以上の足上げを各3回。<br>**公開動画なし** · [記録](evidence/learning-history.json) |

| 第3回 — 参照運動に学習を加える | 第10回 — 慣性を修正して再学習 |
|---|---|
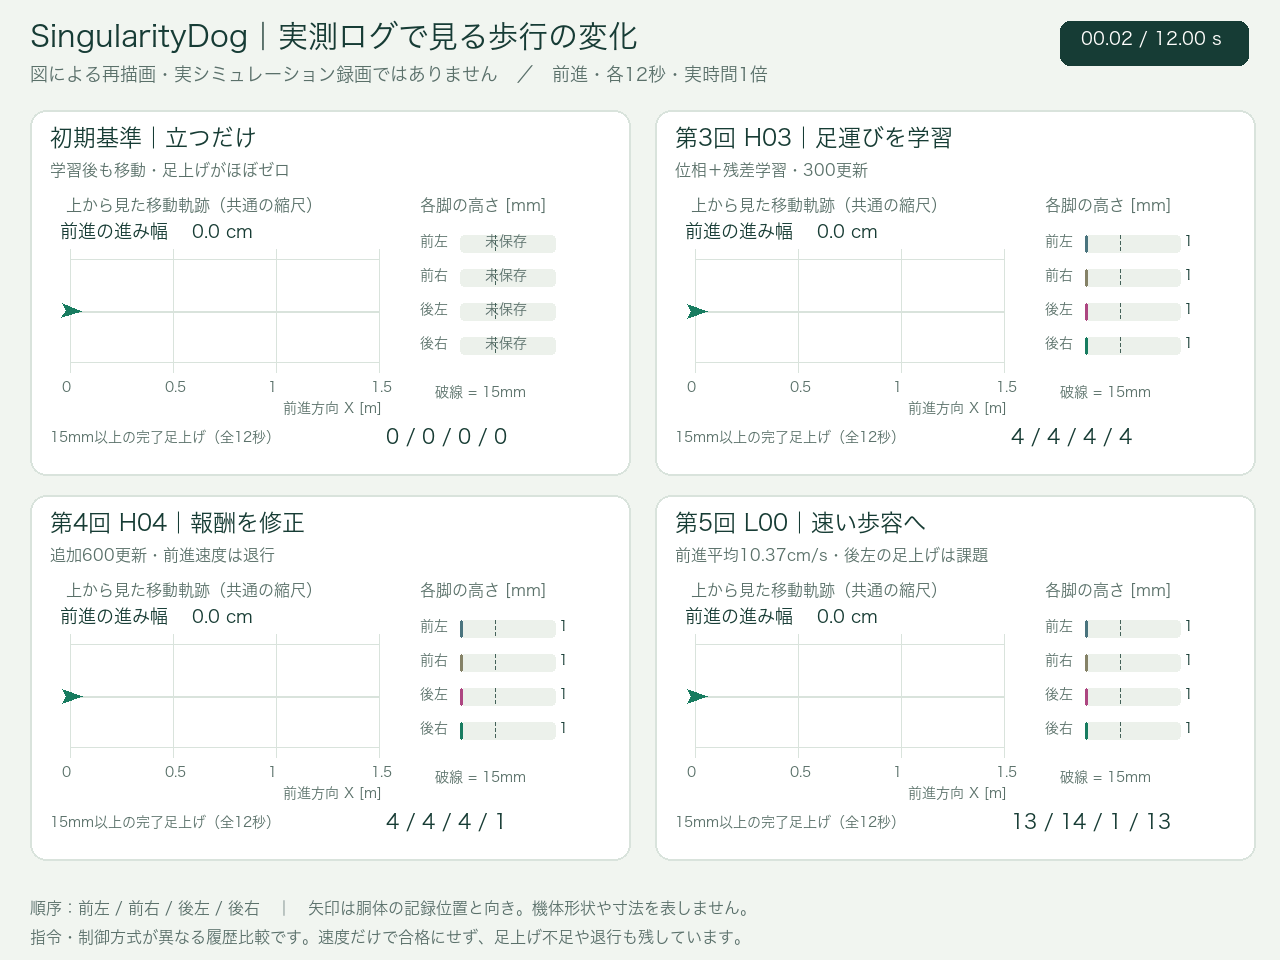
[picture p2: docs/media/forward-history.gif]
第3回を含む初期の前進計測比較チャート。実録画ではありません
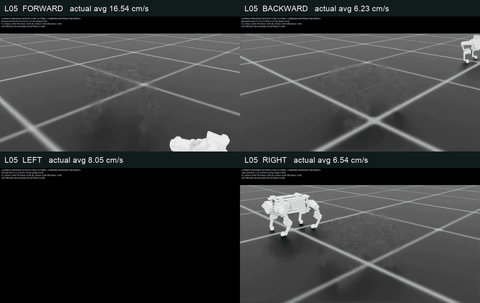
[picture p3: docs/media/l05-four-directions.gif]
第10回の4方向歩行シミュレーション
| <br>300更新で部分的な移動を確認。左後脚の足上げと右移動の接触が課題。<br>[第3回を含む計測チャート動画](docs/media/forward-history.mp4) · [記録](evidence/learning-history.json)<br>※実録画ではなく、初期の複数条件の測定値を再描画。 | <br>前進16.54cm/s。当時の20cm/s目標と足上げの基準は未達。<br>[MP4を見る](docs/media/l05-four-directions.mp4) · [評価](docs/video-history.md#l05第10回の結果動画) |

| 第20回 — 伏せと起立に挑戦 | 第30回 — 9動作を比較 |
|---|---|
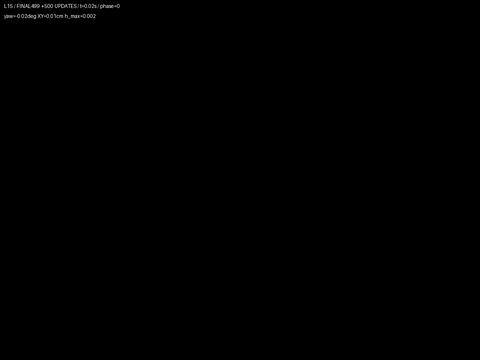
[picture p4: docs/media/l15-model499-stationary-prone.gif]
第20回の伏せと起立シミュレーション
| <br>伏せを2秒ずつ2回保持。起立保持・位置・方位に課題。<br>[MP4を見る](docs/media/l15-model499-stationary-prone.mp4) · [評価](docs/l15-evaluation.md) | <a href="docs/media/l25-a-nine-motions.mp4">第30回条件Aの9動作を3×3で比較したシミュレーション録画</a><br>A/B/C各7/9合格。移動6方向とお座りを達成し、伏せ・挨拶は未達。<br>MP4：[A](docs/media/l25-a-nine-motions.mp4) / [B](docs/media/l25-b-nine-motions.mp4) / [C](docs/media/l25-c-nine-motions.mp4) · [評価](docs/l25-evaluation.md) |

第30回は条件Aの14秒プレビューです。動作名は各画面の左上、先に終了した枠は最後のカラー画像を保持します。合否は全評価区間で判定し、静止表示の時間は成功時間に数えません。9動作は専門方策ごとの個別評価です。

第31〜37回は、伏せ・挨拶の位置や方位の保持を中心に改善を試しました。最新の第37回も位置ずれ50mm以下の基準には届かず、新しい合格モデルはありません。[第37回の結果](docs/l32-evaluation.md)

[全47本の録画・比較動画](docs/video-history.md) · [全1〜37回の履歴](docs/improvement-loops.md) · [節目ごとの結果一覧](docs/milestone-history.md)

## 実機Deployの状況

**Jetson再起動後の無出力501周期（R18）は完了し、独立原本監査PASSです。** 初回20.048744ms・定常500周期最大19.835106ms・処理超過0。有効化・学習目標なし、取得／代理STOPの各周期返信を確認し、別の最終STOP確認はnull。40Vの電源区間は継続し、現在の±3°経路などは直接確認済み。SSH転送／PLAN確認が停止しているため、再起動後のzeroと現条件の2秒・10秒・20秒は未実施です。 先行K12の箱支持2秒は95保存周期・モデル68回で正常終了し、学習目標送信・全12軸最終STOPと独立原本監査PASSを保存しました。その後の10秒はID8有効化返信欠落で0周期となり、全軸STOPの資格が揃わず40VをOff。再投入後のzeroとR16無出力501は監査PASSでしたが、新電源2秒はID7開始角度の候補0件で駆動前に中止し、全12軸STOPを確認しました。後から電源再操作と脚または箱の手動移動が申告されたため、旧姿勢の成功やreviewを現条件へ移し替えません。mix0.005・最大1°・Kp3／Kd0.15、period20msと送信前・native・出力feedbackの20ms制約を維持します。10秒・20秒の完走、全周期20ms、厳密50Hz、絶対精度、荷重支持は未達です。[原本SHAとscope](docs/corrected-output-validation-20261006.md)。

最初の無出力R6は初回20.386889msに既存の初回許容を使用。定常500周期の中央値19.3274065ms・最大19.814066ms、処理と予定終了期限超過0・slot飛ばし0でした。開始間隔257／499区間の厳密20ms超と最大20.080860msは処理時間と分けて残します。その最初のR6は501snapshot・実float32入力・全STOP返信・固定24ソースの独立監査を通過しました。後続の同一K8再計測では、初回20.088333ms、定常処理と予定終了期限超過各1回、開始間隔最大20.243857msを記録し、最初の合格だけでは時刻条件の再現を保証できません。[先行するraw入力の501周期](docs/post-adjust-diagnostic-20261006.md)は最大19.906224ms・超過0で、入力とソースの異なる以前の測定です。

過去の別起動では、箱支持・学習目標0.5%・最大1°の2秒／10秒試験を完走し、全工程20ms以内・全12軸STOP・現物異常なしを確認しました。これらは限定した成功履歴で、最新起動の合格や荷重支持の証明には移し替えません。長時間の通信安定性、四足自立・歩行は未確認です。USB物理切断試験は操作者の指示で省略しました。

| 段階 | 状況 | 次に確認すること |
|---|---|---|
| 印刷 | 完了の報告あり | 装着した部品の版、足先の嵌合、PLA補強部の強度、組立後の重量 |
| 組立・配線 | RS05×12とI2C IMUを確認。USB2CANを前脚／後脚に分割。12軸をFW 0.5.0.13へ更新 | 自動報告を6軸同時に安定して開始できるか再検証 |
| 校正・停止 | 12軸の数値的な枝を現姿勢で照合。新加速度候補を箱支持限定の入力仮説へ選択し、現watchdog200ms・全12軸STOPと実出力を照合。正式校正・絶対原点・姿勢精度は未確定 | 気泡式基準の器差、静止速度の原因、交差軸・温度依存を外部基準で切り分ける。小混合の成功を絶対精度へ置き換えない |
| 駆動・保持 | 4脚の脚別動作と、前脚上脚の顔側約10°・前脚付け根約5°の限定動作を確認。12軸の現在位置保持を前後各100周期完走し、全12軸STOPを確認 | 前脚付け根の10°軌道を再検証し、目標追従と接触の有無を確認 |
| Jetson上の推論 | 先行K12箱支持2秒は95保存周期・モデル68回で正常終了。その後10秒はstartup返信欠落で0周期、新電源2秒は開始角度範囲外で駆動前中止。R16無出力501は定常最大19.860461ms・処理超過0、原本監査PASS | 再起動後R18は501周期・定常最大19.835106ms・超過0、原本監査PASS。現物確認済み。接続とPLAN確認の後、現起動zeroと箱支持2秒を再確認してから10秒・20秒へ進む。厳密全周期20ms・荷重の証明は未達 |
| 立位・歩行 | 未検証 | 支持補助付き立位、荷重移行、低速前進を段階的に検証 |

9月25日の単発3回の実測は、最古入力の取得開始から最終ホスト送信まで**中央値20.063ms・最大20.136ms**、最後の返信まで中央値22.791msでした。送信はSTOP命令による代理測定で、推論した目標角は記録のみです。9月26日の前脚付け根ID3・6の10°試験は、最初の周期で返信の鮮度判定により中断し、完了周期は0でした。全12軸STOPを確認し、操作者に動き・異常・接触は見えませんでした。[9月25〜26日の記録](docs/2026-09-25-26-hardware-status.md) · [9月27日の更新](docs/learned-policy-deploy-status-20260927.md)

9月27日の旧Type17経路は、周期同期後もCAN取得だけで中央値22.183msでした。9月28日のType17並列取得中央値14.93ms、および複合返信を使う100周期の全工程診断とは、経路と測定範囲を分けて記録しています。

以後は **実機計測 → 原因の切り分け → 制御・構造の修正 → 必要なGPU再学習 → 実機再確認** を優先します。[実機移行計画](docs/real-world-deployment.md)

## 現在の課題

今日の作業順・開始結果・残件は[10月6日のToDo・○△×表](docs/today-validation-20261006.md)、K12箱支持2秒の成功と、続くstartup失敗・新電源の駆動前中止・現姿勢の再診断は[新補正の記録](docs/corrected-output-validation-20261006.md)を参照してください。[先行するraw診断と保存モデル比較](docs/post-adjust-diagnostic-20261006.md)、[今週の計画](docs/walking-week-20261005.md)、[10月2日の課題表](docs/resume-20261002.md#コミット時点の課題と修正)は各時点の履歴と計画を残しています。

| 優先 | 課題 | 次の取り組み |
|---|---|---|
| 1 | 新IMU候補を箱支持2秒の実入力へ選択し完走。正式IMU校正、絶対原点・姿勢精度、取付と全可動域の確認は残る | 相対1°の支持付き試験と全域の校正を区別し、限られた試験結果を歩行承認に流用しない |
| 2 | K12箱支持2秒の成功は保持。続く10秒の有効化返信欠落、新電源2秒の開始角度範囲外で中止。電源再操作・手動移動後のR17、その後Jetsonだけの再起動後R18は無出力501周期・原本監査PASS | 現起動zeroと箱支持2秒の完走・全軸停止・直接観察を確認し、その後10秒→20秒。software reviewを現物成功へ転用せず、保持・荷重は別確認 |
| 3 | 新補正の小混合2秒は完走したが、荷重支持・四足自立・歩行は未実施。補助者・遮断担当を分担できるとの回答のみで、新しい荷重操作の予行はまだない | 荷重用保持と補助・遮断の予行を別に確認し、部分荷重、自立、前進数歩の順に実測。2秒成功から箱を外す許可を作らない |
| 4 | 前脚の一部軌道で黄色い部材がカーボンポール固定具に接触 | 接触しない付け根・上脚の経路を現物とCADで確認する |
| 5 | 最新の印刷部品と学習時モデルに差がある | 補強部品・電池配置・質量を現物と照合し、シミュレーションへ反映 |

PLAの割れやナットの入れにくさは設計へ反映済みですが、修正版の印刷・装着・荷重試験の結果をもって解決を判断します。[現在地の詳細](docs/current-status.md)

## ハードウェアライセンス

**本プロジェクト独自の現行機構部品と設計資料を、[CERN-OHL-S-2.0](LICENSE-HARDWARE.md)で公開します。** 製作・改変・販売を認め、改良した設計や製品を配布する際も設計を共有する方式です。改良が公開設計へ還元されることを重視して、Strongly Reciprocal版を選びました。[CERN公式](https://cern-ohl.web.cern.ch/)

対象は[適用ファイル一覧](evidence/hardware-license-scope.json)に明記します。市販モーター・Jetson・電池・ディスプレイの内部設計や商標、第三者のCAD、ソフトウェア、学習済み重み、写真・録画へ一括適用するものではありません。

**現在公開しているのはSTL・BOM・選択した設計資料です。編集用CAD／生成ソースと組立・配線資料の公開は未完了です。** [OSHWAの定義](https://oshwa.org/definition/)に沿った、改変可能な完全ソースの公開を今後の課題として明示します。

<details>
<summary>過去の進捗・資料</summary>

- [節目1・2・5・10・15・20・25・30・35・40の一覧](docs/milestone-history.md)（第40回は未実施）
- [最初に掲載した旧保存番号2197の動画](docs/media/archive-joystick2197-left.mp4)
- [よちよち歩き・第4回](docs/media/h04-forward.mp4)
- [第35回](docs/l30-evaluation.md) · [第36回](docs/l31-evaluation.md) · [第37回](docs/l32-evaluation.md)

保存番号2197は第1回を意味しません。実験回数、学習更新数、動画本数、成功数は別に記録します。

</details>

<details>
<summary>検証ツール・Skills・開発者向け情報</summary>

## Skills

| Skill | 使う場面 |
|---|---|
| [singularitydog-design-study](skills/singularitydog-design-study/SKILL.md) | 荷重経路、重量配置、脚形状、CAD と物理モデルを見直す |
| [singularitydog-rl-iteration](skills/singularitydog-rl-iteration/SKILL.md) | 学習実験を比較し、失敗を観測して次の変更を決める |
| [singularitydog-gait-evaluation](skills/singularitydog-gait-evaluation/SKILL.md) | 速度・各脚の足上げ・滑り・動画から到達点を判定する |
| [singularitydog-experiment-ops](skills/singularitydog-experiment-ops/SKILL.md) | 遠隔 GPU 実験の継続、証跡の固定、知識の引継ぎを行う |

各フォルダを対応するエージェントの skill 検索場所へ配置できます。リポジトリ内の相対リンクと `tools/` も使用するため、まずはリポジトリ全体を取得し、対象の `SKILL.md` を指定して使う方法が確実です。

```text
skills/singularitydog-gait-evaluation/SKILL.md を使って、
今回の実験ログから各脚の足上げと目標速度の達否を確認してください。
```

## 動作確認

基本の6ツールとテストは Python 3.10 以降の標準ライブラリで動きます。追加のアニメーション描画には Pillow・imageio-ffmpeg と日本語フォントを使用します（[描画手順](docs/toolkit.md#readmeのアニメーション)）。

```bash
python -m unittest discover -s tests -v
python tools/audit_urdf.py examples/synthetic_robot.urdf --expected-actuated 1
python tools/evaluate_trace.py examples/synthetic_trace.json
python tools/check_publication.py --root . --files RELEASE_FILES.json
python tools/artifact_manifest.py verify --root . --manifest evidence/release-manifest.json
```

`examples/` はツール検証用の合成入力です。実ロボットのモデル・歩行ログ・学習成果ではありません。

</details>

[検討と判断の記録](docs/decision-log.md) · [公開範囲](docs/publication-scope.md) · [PLA換算重量の過去資料](docs/pla-parts-mass.md)

私物写真・認証情報・接続先は公開していません。

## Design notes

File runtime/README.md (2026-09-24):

# SingularityDog 実機診断ランタイム

Jetson上で12個のRS05とGY-ICM20948V2を調べる初期立上げ用プログラムです。`diagnose`などの診断・校正ツールはモーターを有効化せず、IMUは計測用設定へ一時変更して終了時に復元します。`rs05_joint_trial`と`rs05_leg_trial`は、支持台と電源遮断担当者を必要とする、明示選択した関節の微小駆動試験です。[単関節試験](SINGLE_JOINT_TRIAL.md)・[脚1本の3関節同時試験](LEG_TRIAL.md)を参照してください。

`policy_shadow`は、取得済みの実センサーログで学習済みモデルの起動時推論を確認するファイル処理です。ハードウェアを開く機能やモーター出力はありません。[無出力診断の使い方と仮定](POLICY_SHADOW.md)を参照してください。

`policy_observer`と`telemetry_snapshot`は、時刻付き入力を選び、20ms刻みで方策の状態を保持する無出力の処理基盤です。合成入力で連続更新を検証済みですが、ライブproducerと実機50Hz検証は未完了です。[API・snapshot形式・合成入力の例](POLICY_OBSERVER.md)を参照してください。

[2026-09-21までの実機集計](../docs/hardware-results-20260921.md)：右前脚3関節の限定駆動・停止まで確認済み。公開時のランタイム全体は325件のオフラインテストを通過しています。試験に用いた個体情報・校正候補・生ログ・重みは同梱しません。

## 接続と取得内容

| 機器 | 接続 | 取得内容 |
|---|---|---|
| RobStride USB2CAN / CH340 | `/dev/robstride-usb2can`、UART 921600 8N1 | Type 0識別、Type 17パラメーター読み取り |
| RS05 ×12 | FR 1–3、FL 4–6、RR 7–9、RL 10–12。各脚の足先から胴体の順 | 出力軸位置rad・速度rad/s、電流A、電源V、run_mode、CAN timeout設定、zero_state |
| GY-ICM20948V2 | `/dev/i2c-7`、`0x68`、WHO_AM_I `0xEA` | 加速度m/s²・角速度rad/s、ホスト時刻、読み取り所要時間 |

機種と脚のID対応はユーザー申告です。ID1〜3は右前脚の足先側・中央・胴体側との対応を動作・目視で確認済みですが、他のIDとモデル上の関節名・原点・正方向は未検証です。`run_mode`は制御モードの設定であり、モーターが有効かどうかの判定には使いません。UART速度とCANバス速度も別です。

[ポーズごとの12関節一括保存・基準との比較](POSE_CALIBRATION.md)を追加しました。取得は`joint_snapshot`の読み取りだけ、名前付きの記録と比較は`pose_record`のオフライン処理です。

[Enterで進める手動校正ツール](MANUAL_CALIBRATION.md): Jetson上で位置の案内に従って手で脚を動かし、Enterで保存。各脚5姿勢を続けて記録できます。

IMUは±2g／±250dps、DLPF23.9Hz、約102Hzの設定を100Hzでポーリングします。センサー座標のまま記録し、取付回転・バイアス補正・姿勢推定・磁気センサーはまだ適用しません。最新値を読む方式で、取りこぼし数や変換の厳密な同期は保証しません。

## 実行

Linux、Python3.10以降、pyserial3.5以降が必要です。ユーザーにシリアルポートとI2Cデバイスのアクセス権を設定してください。実機の検証結果は別の立上げ記録を参照します。

[2026-09-20 Jetson実測結果](../docs/hardware-bringup-20260920.md): 60秒計測とSIGTERM時のIMU設定復元を確認。一部設定読取とIMU測定偏差の課題を記録しています。

```sh
cd runtime
python3 -m pip install -r requirements.txt
python3 -m unittest discover -s tests

# 実行計画を表示するだけ。デバイスは開きません。
python3 -m singularitydog_hw.diagnose --seconds 60 --output "$HOME/singularitydog-logs/test-001"

# 実機計測。保存先はGit管理外の、まだ存在しないディレクトリーを指定します。
python3 -m singularitydog_hw.diagnose --execute --seconds 60 --output "$HOME/singularitydog-logs/test-001"
```

`--seconds`は1–120秒の収集時間です。初期化・復元処理と進行中の1リクエスト分は別に時間がかかります。二重起動はI2Cの協調ロックとシリアルの排他オープンで防ぎますが、別のI2Cツールを同時に動かさないでください。

新規ディレクトリーは0700で作り、`events.jsonl`と`summary.json`を保存します。生ログには個体識別情報を含むためGit管理外へ保存します。カメラ画像の取得・アップロードはこのプログラムにはありません。

初回に各IDの識別と設定を読み、続いて位置・速度・電流・電圧を全関節で読みます。全関節の走査は2Hzを目標としますが、応答時間に依存し、制御用サンプリング周期ではありません。タイムアウト後はそのCANセッションを打ち切り、遅れた応答を次の要求の結果として扱いません。

全12個の識別・基本データ・IMUデータが揃わない計測は`INCOMPLETE`です。`can_timeout`と`zero_state`だけは、正しい形式の失敗応答を受信した場合に「設定値不明」の警告として基本データの計測を続けます。この場合は`COMPLETE_WITH_WARNINGS`を返します。失敗応答中の0を有効な設定値として扱いません。無応答・壊れた応答・基本データの読み取り失敗は計測中断になります。いずれの完了表示も歩行可能・安全確認済みを意味しません。

## 停止と次の開発

Ctrl-CまたはSIGTERMで収集を止め、IMU設定の復元を試みます。SIGKILL・電源断・バス断では復元できない場合があります。終了コードと`imu_restore_status`を確認してください。CANの停止命令やtimeout設定変更は送信しません。

`safety.py`は期限切れセンサー、デッドマン解除、校正不足などで出力許可を拒否する純粋な判定器です。診断プログラムでは常に非武装です。物理停止、CAN出力、通信断時の実モーター停止を実装・実証したものではありません。

次は物理的な電源遮断手段と機体支持を確認し、IMUの取付軸と12関節の原点・正方向・可動域を校正します。その後、モーター出力を持たない推論を先に評価し、単関節の制限付き試験、支持付き立位へ進みます。

[校正の手順](CALIBRATION.md)に、IMUだけを記録する`imu_capture`、固定したままの2記録を比較する`imu_fixed_mount_baseline`、関節・停止の確認記録を検査する`commissioning`の使い方をまとめています。`imu_orientation_replay`は独立した静止記録Bを、Aで求めたジャイロbias候補の有無で積分比較するオフライン診断です。絶対姿勢や動作時の精度は保証せず、補正を自動適用しません。六面用`imu_calibration`は必要時の参考として残し、今回の固定IMUで必須にはしません。いずれもモーター出力機能はありません。

## 仕様根拠

- [RobStride RS05公式マニュアル](https://github.com/RobStride/Product_Information/blob/main/Product%20Literature/RS05/RS05User%20Manual260713.pdf) のパラメーター読み取りとデータ型。
- [RobStride USB変換ソフト](https://github.com/RobStride/CAN-USB-data-conversion/blob/main/switch/mainwindow.cpp) のバイナリーATフレーム。
- [TDK ICM-20948データシート](https://invensense.tdk.com/wp-content/uploads/2024/03/DS-000189-ICM-20948-v1.6.pdf)。実装上の制限は[IMUの詳細](IMU_IMPLEMENTATION_NOTES.md)を参照。
- [停止判定器の詳細](SAFETY_IMPLEMENTATION_NOTES.md) · [実機開発方針](../docs/real-world-deployment.md)

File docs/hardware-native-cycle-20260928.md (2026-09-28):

# 9月28日：Jetsonの取得・実推論・送信の実測

**最新の無駆動診断候補r13は500周期を完走し、最古入力→最終ホスト送信は中央値15.667ms・最大18.469msで全周期20ms以内だった。最後のSTOP返信は14／500周期、返信後処理を含む全工程は16／500周期が20msを超え、全工程最大は21.640ms。** 周期内の記録を事前確保領域へコピーする24要求STOP代理診断である。継続50Hz・学習目標の実送信・立位の合格にはしない。以下にr6〜r13の測定条件と全完了条件を残す。

r7の履歴：**0.8ms間隔を維持し、プロセスのtimer slackを1µsへ減らした単独比較100周期では、実入力から最後の返信まで全100周期20ms以内だった（中央値18.74ms、最大19.64ms）。返信後の検査まで含む周期完了は中央値18.97ms、最大22.22msで、2周期が20msを超えた。** 後続の全工程GC比較も各100周期完走したが、全周期20msには未達である。0.7msは23周期完了後にID9の返信が欠けて中断したため、現時点で採用しない。今回はモーターを有効化せず、学習目標の代わりにSTOPを送る診断である。立位・歩行、Type1の実目標送信の合格ではない。

支持台上・脱力・手離し・即時40V Offを操作者が確認。付け根ID3/6/9/12を水平側へ整えた後、12軸のUID・角度を新しく取得した。学習モデルの数値範囲には全12軸が入った。物理原点・正方向・可動域の正式レビューは引き続き必要。

## 並列取得の比較

前脚6台・後脚6台・I2C IMUを3スレッドで取得。Type17では位置と速度を別々に読み、各バス12要求。送受信は同じJetsonでビルドしたC++を使用する。各条件20周期、再送なし、100msの受信期限は共通である。

|未返信上限／送信間隔|取得中央値|取得最大|結果|
|---|---:|---:|---|
|1／0.6ms|33.47ms|33.93ms|20周期完了|
|2／1.0ms|20.11ms|21.04ms|20周期完了|
|3／1.0ms|**14.93ms**|**15.01ms**|20周期完了|

未返信上限3／0.6msの旧試行では返信が欠けた。全要求が送られた後、期限まで待っても未返信だったため、単に待ち時間を延ばす修正は採用しない。起動時のUID照合は1台ずつにし、周期内の上限とは分けた。CAN物理層の実ボーレートはこの測定では証明していない。

## 複合返信と全工程

独立したType17の前後読取りでSTOPのType2返信を挟み、全12軸が3回とも静的比較を通過した。位置差の最大は0.02275°、速度差の最大は0.11809rad/s。前の比較でID11の静止判定が1回不確定だった記録も保持しており、判定値は変更していない。静止での一致は動的速度倍率・トルク換算の承認には使わない。

全工程ではType2の1返信から位置・速度を組み立て、IMUとともに実モデルへ入力し、推論後に12軸へSTOPを送った。取得側12要求と出力側12要求、前後バス並列である。

以下はr6の20周期比較で、後述のr7・100周期と履歴を分けている。

|条件：上限3、20周期|取得中央値|入力検査・実推論中央値|最古入力→最終ホスト送信 中央値／最大|周期完了 中央値／最大|20ms超過周期|
|---|---:|---:|---:|---:|---:|
|1.0ms、通常CPU設定|8.50ms|7.78ms|22.97／23.50ms|26.18／26.68ms|20/20|
|1.0ms、一時的performance|8.28ms|4.17ms|**18.51／19.66ms**|21.54／23.51ms|20/20|
|0.8ms、一時的performance|7.23ms|4.11ms|**16.47／18.26ms**|**19.51／21.75ms**|5/20|

別に入力組立てが各中央値0.72／0.37／0.37msかかる。各段の中央値を足した値を全工程の中央値とみなさず、生時刻から計算した結果を掲載した。最終ホスト送信はUSB書込み復帰時刻であり、CAN線上の送信完了ではない。0.8ms条件の最終返信までは中央値19.26ms、最大21.05ms。開始間隔の最大は21.83msで、21ms以内の条件も未達だった。

0.6msの複合返信試行でも前脚ID2/6が欠測したため、その条件は採用しない。performanceの最初の準備試行は子プロセスのキャッシュ先権限で計測前に終了した。修正版ではユーザー環境を適切に引き継ぎ、CPU設定復元まで確認した。これらの中断を成功試行へ混ぜていない。

CPU上限・下限を変えず、2つのCPUポリシーを測定中だけ`performance`へ変更した。終了時には両方`schedutil`へ戻り、証跡で読戻しを確認した。実モデル呼出しは中央値5.817→3.141ms、コピーやハッシュ処理も短縮した。同じ計算コードで速度が戻ったため、モデル演算の削除よりCPU動作条件の影響が大きい。

## r7：スレッド準備後の100周期と0.7ms比較

前脚・後脚・IMUの3スレッドを最初の周期より前に起動するよう修正した。準備時間は0.8ms試行で1.549898ms、0.7ms試行で1.588013msで、周期とは別の`worker_startup`記録に保存した。準備中に機器取得・推論・送信はせず、各周期の取得・推論・返信後検査の計時は維持した。統合・CLI・周期境界の73テストが通過している。

同じ起動・入力設定・C++バイナリ・実モデルを使い、未返信上限3、100周期を指定した。CPU設定は両試行とも一時的な`performance`で、上限・下限は変更せず、正常終了・途中中断のどちらでも2ポリシーが`schedutil`へ復元された。

|r7条件|完了／要求周期|取得中央値|入力検査・実推論中央値|最古入力→最終ホスト送信 中央値／最大|周期完了 中央値／最大|結果|
|---|---:|---:|---:|---:|---:|---|
|0.8ms|100／100|7.25ms|4.05ms|**16.36／17.17ms**|**19.36／23.10ms**|欠測なし、周期完了20ms超過5／100|
|0.7ms|23／100|6.81ms|4.16ms|15.54／16.60ms|18.54／19.95ms|第24周期の取得側・後脚ID9未返信で中断|

設定値は要求間の最短待ち時間であり、実間隔とは分けている。完了した通信区間の前のwrite復帰→次のwrite開始は、0.8ms設定で中央値0.858391ms、0.7ms設定で0.759990msだった。最後のwrite後から最後の返信までの中央値は各2.770203／2.775184msで、間隔短縮だけではこの待ちは減っていない。

0.7ms行の時間・超過0は、完了した23周期だけの統計である。第24周期は後脚の6要求を送った後も返信が5台分しかなく、100ms期限で中断した。前脚取得とIMUの記録は残ったが、同周期の推論・出力には進んでいない。欠測周期を除いた最大19.95msから、100周期の安定動作や全工程20ms達成とは判断しない。自動再送は行っていない。この2試行だけで、間隔を0.7msへ短縮したことが欠測の原因だとは断定しない。

0.8msの周期完了p95は19.802197ms、p99は20.196159ms。最終返信までは中央値19.1158575ms、最大22.582687msで、開始間隔は最大23.186992ms（21ms超過1回）だった。最大の第34周期ではホスト送信まで16.349143ms、推論4.056493msと通常域にあり、送信後から最後の返信までの待ちが伸びた。USB・CAN・QDDのどこで待ったかは未特定である。他の超過には推論が4.7〜4.9msへ伸びた周期もある。**0.8msを比較の基準にし、推論と受信待ちの変動を分けて改善する。** 100周期完走は通信の限定確認であり、長時間の実出力や荷重保持の承認ではない。

## r7：timer slackの有限比較

0.8ms・未返信上限3・受信期限・各種検査・STOP代理の24要求を維持し、CPUは上限・下限を変更しない一時的な`performance`とした。最初に通常の50µsで20周期、続いて1µsで20周期、欠測がなかったため1µsで100周期を測った。要求間隔を0.7msへ変更した試験ではない。

|timer slack|完了周期|最古入力→最終ホスト送信 中央値／最大|最古入力→最後の返信 中央値／最大|周期完了 中央値／最大|20ms超過周期|
|---|---:|---:|---:|---:|---:|
|50µs：比較基準|20／20|16.47／17.34ms|19.27／20.04ms|19.53／20.43ms|1／20|
|1µs：短い比較|20／20|16.01／16.85ms|18.79／19.63ms|19.04／20.07ms|1／20|
|1µs：100周期|100／100|**15.96／16.87ms**|**18.74／19.64ms**|**18.97／22.22ms**|2／100|

全試行で12台の取得・出力返信に欠測はなかった。1µsの100周期は取得中央値7.037655ms、推論中央値4.091678ms、周期完了p99は20.052995ms。第1周期は推論が5.069483msへ伸び、周期完了20.052995msとなった。最大の第34周期では最後の返信まで18.611072msだったが、返信後から周期終了まで3.441344msを要した。周期開始→最古入力開始の0.165736msも全工程に含む。今回は**返信後の回収・スレッド受渡しを含むホスト側処理**に最大周期の待ちが残り、以前の第34周期のUSB/CAN/QDD返信待ちとは分けて調べる。開始間隔は最大22.322445msで、21ms超過1回も残る。

timer slackはLinuxの`pselect`等で許されるタイマーの遅れ幅である。新しいスレッドは作成元の現在値を引き継ぐため、周期前の3スレッドすべてで設定値を読戻した。[Linux man-pages：PR_SET_TIMERSLACK](https://man7.org/linux/man-pages/man2/PR_SET_TIMERSLACK.2const.html) 主スレッドは50,000ns→1,000ns→元の50,000nsへ復元し、CPU2ポリシーと周波数上限・下限も復元済み。これは有限の比較用ラッパーによる測定であり、標準ランナーの恒久設定にはしていない。中央値の改善を全周期20msの合格へ置き換えない。

## 保存入力だけでのCPU・GC比較

実機から保存済みの20入力を6試行、計120回再生し、各出力と試行後の内部状態の厳密一致を確認した。機器は開かず、取得・送信・周期完了を測った試験ではない。連続呼出しの推論中央値は2.827〜2.852ms、呼出し間に15ms置いた場合は3.013〜3.032msだった。遅い呼出しの壁時計4.730／4.853msに対し同じ主スレッドのCPU時間も4.562／4.723msで、待ち時間だけを削れば解決するとは判断できない。

|保存入力でのGC比較|呼出し数|連続呼出し中央値／最大|15ms待ち中央値／最大|自動GCイベント|
|---|---:|---:|---:|---:|
|observe|120|2.808／4.337ms|3.013／4.325ms|0|
|defer|120|2.876／4.267ms|3.085／5.046ms|0|

両条件とも自動GCイベントは0で、GC状態・一時的CPU設定・周波数範囲の復元と出力／内部状態の一致を確認した。この比較は保存入力の推論中心の測定であり、実機の返信回収を含む全工程のGC原因を証明・否定しない。実行時のGC無効化は採用していない。

別のファイルのみの比較では、推論中に繰り返し作るテンソルviewを事前生成した候補を検査した。各版120呼出しの推論中央値は2.711110→2.571104ms、主スレッドCPU中央値は2.688336→2.551824msだった。240合成フレーム・保存入力120回／版・26拒否ケースを確認し、目標・内部状態・再ロード後の状態が厳密一致した。約0.14msの候補改善であり、取得・送信を含む20ms達成ではない。旧ローダーへ暗黙に差し替えず、診断用の明示的な候補として保持する。

## 全工程のGC観測と遅延比較

保存入力だけの測定と分け、0.8ms／上限3・timer slack 1µsで、取得・推論・返信回収を含む100周期を通常GCの観測と有限のGC延期で各1回測った。両方100／100周期、12軸の取得・出力返信に欠測はなかった。

|全工程のGC条件|周期完了中央値／最大|20ms超過周期|GC回収|
|---|---:|---:|---|
|observe|18.885／21.946ms|3／100|世代0が11回、各0.176〜0.227ms|
|defer|19.073／21.460ms|1／100|観測中0回|

通常GCの超過は第1・6・24周期で、GC回収の時刻とはすべて重ならなかった。延期した比較も第1周期の推論6.099758msにより超過した。最大値と超過数は変わったが、中央値は短縮せず、この1組だけでGC延期の因果的な改善や全周期20ms達成とは判断しない。CPU・周波数範囲・timer・GC状態を復元済みで、標準ランナーのGC無効化は採用しない。タイマー単独比較の最大周期の返信後3.44msについても、このGC比較だけで内部原因が確定したとは言わない。

## r8〜r12：準備処理と500周期への延長

全条件で前後CAN・IMUを並列取得し、送信間隔0.8ms／未返信上限3、一時的CPU performance、timer slack 1µsを用いた。周期内は取得12＋出力12の24要求で、出力はSTOP代理のみ。全試行で全12軸の取得・出力返信に欠測はなく、CPU governor・周波数範囲・timer・IMUを復元した。GC・CPU固定の比較も元の状態へ復元済みである。モデルのwarmupはUID照合・IMU開始後、周期開始前へ移した。

|条件|完了周期|全工程 中央値／最大|20ms超過|最終ホスト送信 最大|最後の返信 最大|開始間隔21ms超過|
|---|---:|---:|---:|---:|---:|---:|
|r8：warmup位置変更|100／100|19.120／23.051ms|2|16.852ms|19.635ms|1|
|r8：テンソルview再利用|100／100|18.931／21.460ms|1|16.643ms|19.363ms|1|
|r8：同候補＋通常GC観測|100／100|18.926／21.716ms|1|16.439ms|19.237ms|1|
|r8：準備時GC＋同候補|100／100|18.890／19.778ms|**0**|16.536ms|19.332ms|0|
|r8：同じ準備条件を延長|500／500|18.792／21.593ms|**8**|18.547ms|21.268ms|5|
|r8：GCを有限で延期|500／500|18.890／21.226ms|20|18.248ms|21.001ms|4|
|r8：GC延期＋CPU固定|500／500|30.712／32.395ms|500|29.283ms|32.108ms|499|
|r9：公開コードの準備時GC＋コピー削減|500／500|**18.740／21.041ms**|**10**|**18.004ms**|20.780ms|4|
|r9：別試行のCPU・GC追加計時|500／500|18.829／21.752ms|19|18.691ms|21.461ms|8|
|r10：循環参照を作らないイベント複製|500／500|**18.807／22.342ms**|**4**|16.592ms|19.379ms|4|
|r10：一時的なCPU上限1,728,000kHz|500／500|18.132／20.894ms|4|16.974ms|19.704ms|0|
|r11：選択式の周期内記録エンコード|500／500|19.293／21.331ms|4|17.706ms|20.477ms|1|
|r12：r11の記録方式＋一時的なCPU上限1,728,000kHz|500／500|18.619／21.635ms|16|18.109ms|20.953ms|2|
|r13：事前確保した記録領域への周期内コピー|500／500|18.792／21.640ms|16|18.469ms|21.295ms|6|

準備時GCの100周期は全工程20ms以内だったが、同条件の500周期で超過が戻った。成功した100周期だけを継続制御の証拠として採用しない。r8の8個の受領ディレクトリにはGC観測の同じ100周期の複製が1つ含まれ、report・recordsのSHAが一致したため、独立した試行は7条件として数えた。r12までの全完了条件の数値と原本SHAは[集計JSON](../evidence/hardware-native-cycle-20260928.json)へ保存した。

通常GC観測の第94周期では、世代1の回収2.853430msが最後の返信後の区間に重なり、周期完了21.716324msになった。準備時GC後の500周期でも、第101・208・315・422周期に世代1回収2.411〜2.515msが重なり、別の4超過周期では推論5.547〜6.449msへ伸びた。以前のr7で世代0の回収が超過と重ならなかった結果は、その測定条件の履歴であり、より高い世代のGCによる遅延を否定するものではない。

GC延期の500周期は20回超過したため、周期中のGC停止は採用しない。CPU固定は親と通信workerを含むプロセス全体をCPU4の1コアへ固定した条件で、全500周期が超過した。モデル呼出しの壁時計中央値14.787msに対して主スレッドCPU中央値4.627msだった。主スレッド以外の計算を含まないCPU時間との差だけでは内部原因を断定できないが、この全スレッド1コア固定方法は採用しない。推論だけを別コアに固定する将来のファイル比較とは条件を分ける。

r9では`--setup-gc before-warmup`を明示した場合だけ、UID照合・IMU開始後、warmupより前に全世代GCを行う。実測127.973175msは準備時間として別記し、周期内に隠していない。GCの有効状態・閾値は変更せず、既定ではこのGCを実行しない。周期内の重複コピーも減らし、183保存フレームの2入力経路・h=0/1で出力・内部状態・失敗記録が厳密一致した。ファイル比較の50件の対象テストとCLIの58件は通過したが、重なる範囲の件数を加算せず、実機20msの証拠と区別する。

r9の500周期へCPU区間と通常GCの計時を追加した別試行では19回超過し、世代0回収70回・世代1回収6回を観測した。世代1の1.707〜2.111msは第75・156・236・314・394・472周期の超過に重なり、主に来歴のシリアライズ区間へ現れた。他の遅いモデル呼出しでは主スレッドCPU時間も伸びたため、待ち時間だけが残件ではない。この試行は計時の負荷を含み、公開コードそのままの500周期・10回超過を代表値として残す。全超過をGCかモデル計算の一方へまとめない。

r10ではイベント複製の再帰関数が作る循環参照を除いた。保存済み183フレームの両仮説と20件の失敗系列について、値・状態・拒否理由を旧版と比較し、対象52テストが通過した。単独の割当検査では、旧版で残る到達不能オブジェクトが新版では0になった。この検査は遅延の原因を確定しない。通常GCを有効にした実機500周期では、最後の返信まで全周期20ms以内になったが、第112・231・350・469周期に返信後2.566〜3.117msの遅延があり、全工程4回超過した。約119周期の間隔は原因の証明ではない。原本report・recordsと比較根拠のSHAは[集計JSON](../evidence/hardware-native-cycle-20260928.json)に保存した。

CPU上限を1,497,600→1,728,000kHzへ一時的に上げた別500周期では、推論中央値が3.915→3.370ms、全工程中央値が18.807→18.132msに変わったが、同じ第112・231・350・469周期で最大20.894ms・4回超過した。CPU上限だけでは返信後の遅延は消えない。直後の設定読戻しでは後側CPUの上限復元を確認できず、保存済みの原記録はそのまま残した。その後の再読取りで両CPUのgovernor・最小・最大周波数が試験前と一致し、追加の書込みなしで復元を確認した。一時的な最高周波数は標準設定に採用していない。

r11の選択式記録エンコードを使ったSTOP代理は500／500周期を完了した。取得は中央値7.034448ms・最大7.428236ms、推論は中央値3.899691ms・最大5.996260ms。最古入力→最終ホスト送信は中央値15.692525ms・最大17.705797msで20ms超過0回、最後のSTOP返信までは中央値18.483337ms・最大20.477105msで2回超過した。返信後処理を含む全工程は中央値19.292784ms・最大21.330889msで4回超過し、開始間隔21ms超過は1回だった。r10の周期的な返信後の大きな遅延はこの試行では減ったが、通常の周期処理は増え、原因は確定していない。モーター有効化と学習目標送信はなく、一時的なCPU設定は元に戻した。非公開原本reportのSHA-256は`b0525b782f29de76171c48dd20cafd0ba1a546a2f1d3e73464766991059cf448`。継続50Hzや実出力の合格にはしない。

r12はr11と同じ起動条件で、CPU上限だけを測定中に1,728,000kHzへ上げた別の500周期だった。取得は中央値7.0093265ms・最大7.423368ms、推論は中央値3.413709ms・最大5.998216ms。最古入力→最終ホスト送信は中央値15.110486ms・最大18.10889ms、最後のSTOP返信までは中央値17.899989ms・最大20.952699ms。全工程は中央値18.6192055ms・最大21.634537msで16／500周期が20msを超え、開始間隔21ms超過は2回だった。r11より中央値は短くなったが、最大値と締切超過数は悪化したため、CPU上限引上げは採用しない。モーター有効化と学習目標送信はなく、CPUのgovernor・最小・最大周波数は試験前の値への復元を読戻しで確認した。非公開原本reportのSHA-256は`7a1466d2e7ed5535f475bafc320d5678a4100061a3a5b3bcabea9c2f9a155c01`。継続50Hzや実出力の合格にはしない。

r13は通常のCPU上限1,497,600kHzへ戻し、r11から周期内の記録方式だけを変更した。500周期の全軸取得・STOP代理返信が揃い、最古入力→最終ホスト送信は中央値15.667ms・最大18.469msで全周期20ms以内だった。最後の返信は中央値18.446ms・最大21.295msで14回、返信後処理を含む全工程は中央値18.792ms・最大21.640msで16回超過した。返信後→周期終了の中央値はr11の0.660msからr13の0.185msへ短縮した一方、r13の超過16回中12回は入力検査・モデル呼出し・結果変換を含む`inference_ms`が5ms以上で、最終ホスト送信後の返信待ち約2.7〜2.9msも残る。独立した2試行なので、超過数4→16の変化を記録方式だけの因果効果とはしない。記録バッファのコピーは周期時間に含み、詳細JSON化は全周期後に行った。CPU設定・IMU設定の復元を確認し、モーター有効化・学習目標送信は行っていない。非公開原本report／records／CPU復元記録のSHA-256は順に`fc3732f9639808f225a1fd30618ed1da3f2a49a8f38cced5e9a95fa2e1983376`／`3832ceffee959e8442e079785d4e0e39ab8a1343e960aa15721d24b0cdda4ca4`／`5a48add0e88fc07bd0956e0d10dbc6a914328dda724d78764bce0000edba0e06`。まだ全周期20ms・実出力26／28要求・荷重保持の合格ではない。

同じr12の500入力を、CAN・IMU・モーターを開かない別プロセスで3回ずつ再生した。各回で保存目標・actor出力・観測74値が完全一致し、候補モデルと基準モデルの内部状態も全500周期で厳密一致した。20ms間隔の再生では推論呼出し中央値5.268／5.334／5.342msだったが、待機中にCPU周波数が下がる条件を含むため、実機統合周期の推論時間と直接比較しない。連続再生では中央値2.822／2.809／2.807ms、最大5.141／4.568／7.870msで、4ms超の周期は各8／1／3件だった。3回に共通する遅い入力番号はなく、遅い呼出しではスレッドCPU時間も増えた。入力固有の計算分岐や単純なスケジューラ待ちだけでは説明できず、演算内訳・CPU移動・周波数変動を次に分けて測る。連続再生の非公開原本SHA-256は`80fc176e1908bde3a45def903290a3a96dcc854a7638787d2d63598fd604e93b`。この再生は推論だけで、CAN取得・STOP送信・20ms周期の合格ではない。

続いて同じ保存500入力を演算別に調べた。元のforwardの計時区間外でCPUコアと周波数を読み、プロファイラを掛けない476呼出しの中央値は2.708ms、最大5.317msだった。遅い第125〜128呼出しはCPU0に留まり、初回の直前には同クラスタの周波数が729,600kHz、以後は1,497,600kHzを示した。少なくともCPU4/5への移動だけでは遅延を説明できないが、呼出し中の周波数変化はこの前後サンプルから判断できない。独立した500件の3段分解では観測組立て0.536ms、actor 0.850ms、目標計算1.496msが中央値で、目標・観測・actor・内部状態はすべて厳密一致した。最初の2件に外部メソッドの初回特殊化と整合する大きな遅延があり、定常分布へ混ぜない。24呼出しのPyTorch演算プロファイルではactorの`aten::addmm`が合計約22msだったが、プロファイラ自体が処理を遅くするため、この値を通常の周期時間へ直接足さない。非公開原本SHA-256は`0b361dd91bab3ee651b4e852d1270ecc664d47351e8f51f3ca7233ec0f288673`。CPU固定やC++置換は、この結果だけでは採用しない。

R13と同じview-cacheモデルをR12保存500入力でファイルのみ再生し、PyTorchの演算スレッド1／相互スレッド1（統合ランナーの設定）と2／1を各2回比較した。保存目標・actor・観測74値は全2,000呼出しで厳密一致し、各条件500周期で基準モデルとの目標・内部状態も厳密一致した。1／1のモデル呼出し中央値は2.579／2.573ms、p99は2.993／2.856ms、最大は4.687／3.470ms、4ms超は2／0回。2／1では中央値3.196／3.176ms、p99は4.380／4.162ms、最大は6.731／4.497ms、4ms超は13／21回へ悪化したため、2スレッド化を統合試験に進めない。CPU設定は変更せず、試験後の両ポリシーは`schedutil`・729,600〜1,497,600kHzで、CAN・IMU・モーターは開いていない。非公開原本SHA-256は1／1が`430801ab0bde673da33c6c16740437d7ca863ac73c46725b4f61e3aa968576f5`、2／1が`cd6386cb883aa5cddf586220900b45729ee5d906e62059cf2a1b989b657652e1`。これは保存入力での推論比較であり、R13の統合周期や実出力の改善実測ではない。

目標計算内のテンソルコピーを一つ省く候補も、保存入力500件の目標・actor・観測・全内部状態と26拒否ケースの厳密一致を確認してからMacで比較した。4組の交互測定の中央値は基準0.424125ms、候補0.426521msで、候補が僅かに遅かったため採用しない。Jetson実機の全工程や実出力を測った結果ではない。

r13の保存済み500周期のobserver区間記録を再集計した。`inference_ms`はモデル単体ではなく`observer.consume()`全体であり、中央値3.814msのうちモデル呼出しは2.906ms、残る区間は0.874msだった。全工程超過16周期のうち推論5ms以上の12周期は、すべてモデル呼出しも4ms以上（4.249〜5.232ms）で、その12周期の残るobserver区間は中央値0.890msだった。長い区間は主にモデル呼出し内にあるが、演算・割当・CPU周波数のどれが原因かはこの記録だけでは決まらない。

native projectionの出力割当を9テンソルから、推論の`step_target()`が使う`solved`と`applied`の2テンソルに絞る別のファイル専用候補をMacで比較した。C++の幾何計算と後段の検査は維持し、保存入力500件で目標・actor・観測・全named stateが毎回厳密一致し、26拒否ケースも一致した。500件×4回の交互測定でforward壁時計の基準／候補は中央値0.428750／0.426500ms、p99 0.467625／0.465084ms、最大0.556125／0.567208msだった。p99の差は小さく最大値は悪化したため採用しない。原本ソース・測定値は非公開の`native-projection-output-candidate-r1`へ保存し、`mac-result.json`のSHA-256は`334b7e050f9d4343dc0bfe97ebf69c8f7ce22396d799c2bcf4bb9c6038553799`。Macの保存入力forwardだけの結果であり、Jetson上の長い周期、CAN・IMU取得、STOP代理送信、全工程20msや実出力は測っていない。

r11／r12の実機周期では、推論終了→最終ホストwrite復帰の中央値が4.399／4.355ms、最終write→最後のSTOP返信が2.792／2.786ms、返信後→周期終了が0.660／0.580msだった。生の各write時刻を分解すると、両バスの遅い方で6要求の5間隔×0.8ms＝4.0msが固定下限、推論終了から最初のwriteまでは中央値0.283／0.254msだった。このうちC++交換関数に入る**前**が0.268／0.242msで、ネイティブ内の最初のwrite待ちは0.015／0.013msに過ぎない。実間隔の中央値は0.810／0.809msである。r12の16超過周期は推論が4.849〜5.998msに伸びた区間と重なった。送信側の未最適化部分をすべて消す仮定でも中央値で約0.3msの余地しかなく、実出力のキャンセル・起動確認・返信照合を削ってこの値を狙わない。0.7ms間隔は別試行で返信欠落があり採用していない。

r13の500周期生レコードを[再利用可能なファイル解析器](../tools/analyze_native_output_latency.py)でも分解した。各バス6要求の初回→最終write復帰は前／後の中央値4.093／4.095ms、要求間の実際の待ちは0.810／0.810ms、`write()`のホスト呼出し自体は両方とも中央値約0.007msだった。最終write復帰→最後の返信に対応する`read()`開始は2.765／2.771ms、`read()`開始→読取り完了は各約0.002ms。したがって残る約2.77msはPythonの返信デコードより前にあり、ホスト時刻だけではUSB基板・CAN線・QDDのどこで待ったかを決められない。0.8msを未確認の0.7msへ下げたり、返信を省いたりする理由にはしない。解析原本は上記r13の`records.json` SHAに結び付け、私有コピーへ保存した。

このJetsonで前後の`ttyUSB`は両方`ch341-uart`で、FTDI式の`/sys/bus/usb-serial/devices/ttyUSB*/latency_timer`は存在しなかった。`setserial`も現環境には入っていない。[LinuxのCH341ドライバー実装](https://github.com/torvalds/linux/blob/master/drivers/usb/serial/ch341.c)にはFTDI式のlatency timer設定がない。したがって、未確認の`latency_timer=1ms`や`setserial low_latency`を今回の約2.77ms待ちの修正として扱わない。USB/基板/CAN/QDDの内訳を知るには、別のハードウェア時刻計測が必要である。

R12の保存500入力をJetson上でCAN・IMUを開かずに再生し、モデル呼出しの主スレッドだけをCPU0またはCPU4へ固定して各2回比較した。PyTorchの演算／相互スレッドはいずれも1、両条件で保存目標・actor・観測・全内部状態は完全一致した。CPU0の中央値は2.475／2.479ms、p99は2.736／2.708ms、最大は3.142／3.419ms。CPU4は中央値2.438／2.443ms、p99は2.545／2.525ms、最大は2.768／2.778msで、保存入力の上側の遅延は小さくなった。ただしこれは単独推論の比較で、3本の取得スレッドやUSB待ちが同時に走る実機周期の改善をまだ示さない。全スレッドを1コアへ固定した以前の試験は500周期すべて20ms超過だったため、次の診断では主スレッドだけを固定し、I/Oスレッド3本が従来のCPU集合を維持することを計測前に確認し、終了時は主スレッドの設定を復元する。復元できなければ試験を中断扱いにする。保存入力の原本SHA-256はCPU0 `bc7965f184c29014beb6123bd42988b4c84aec827339869be42b14e57afab43a`、CPU4 `d3afdc858d171c63c7eb077ba7b6fe0dc5163f68754eb7c9c3e5a70bd56236b3`。20ms達成や実出力の合格にはしない。

固定17バイト返信の解析、observerの静的来歴の再利用、主スレッドだけのCPU4固定と復元を含むR14診断キットを、R13とは別のJetsonディレクトリへ配置した。387 manifestファイルを照合し、Jetsonの関連211テストとMacの全体1782テストが通過した。診断C++ transportはR13と同一ソース・同一ターゲットバイナリで、キットmanifestのSHA-256は`6886e31e1d366af1fb7819d604534a7c90f0e05226e2cea178bf26ae26ee79ba`。R13の保存起動命令からキット内パス・新しい出力パスと`--main-thread-cpu 4`だけを変える一回限りのラッパーをMac側で構文・差分検証した。その後Jetsonで現起動の12軸を読取り専用で再記録し、R14の無駆動500周期を完走した。最終ホスト送信は超過0、最後の返信は6、周期完了は9、21ms超の次周期開始間隔は6件。周期完了の中央値18.640ms、最大22.182msで、20ms合格には至らなかった。CPU設定と主スレッドaffinityの復元を確認した。モーター有効化と学習目標送信は行っていない。

参考としてR13の各周期から一律に時間を引く仮計算では、周期完了の最大21.640msを20ms以下にするには最悪周期から少なくとも1.640ms、最後の返信の最大21.295msには1.295msが必要だった。全周期から0.5ms引いても周期完了13／500件、最後の返信7／500件が20msを超える。この仮計算はR14やC++候補の予測結果ではなく、尾部で必要な改善幅を表すだけである。保存入力のC++再帰step融合はMacでモデル呼出し中央値を0.442→0.405msにしたが、Jetsonの厳密一致試験はSSH切断で結果未回収で、現時点ではこの候補をR14へ組み込まない。

500周期の超過16件を[保存記録の分類器](../tools/analyze_native_cycle_misses.py)で分けると、12件はobserver推論が5ms以上、3件は推論終了から両バス共通のC++送信関数に入る前の待ちが2.875〜3.113ms、残り1件は第1周期だった。共通待ちの3件は第124・256・388周期で132周期ずつ離れている。通常の同区間中央値は0.216ms、C++関数に入ってから最初のwriteまでは約0.02msなので、この3件をUSB送信処理そのものやC++解析へ帰属しない。周期性はPython GCを疑う材料だが、GC時刻は未記録で原因と断定できない。次版では安全判定を変えずに、送信前のチェック・ワーカーへの投入・GCイベントを分けて記録する。分類結果は非公開の生記録SHAに結び付けて保存した。

次版候補へ明示選択の`--output-dispatch-trace`を実装した。推論終了、mainのチェック、前後ワーカー投入と入口、C++開始、最初のwrite、mainスレッドCPU時間、GC開始・終了を事前確保の固定長配列に保持し、試験後にまとめて出力する。対象97テストで従来の既定経路、モデル拒否時のSTOP不送信、GCフックの解除を確認し、Macの全1786テストも通過（4件skip）した。これだけをR14から変更したR15診断キットも387ファイルを照合してJetsonへ別配置し、アーカイブSHA-256を`c8e83a1346cc32bccccbc3306c70a28839294779d4e95d55b5dd646116deaf12`に固定した。R15の無駆動500周期は最終ホスト送信超過0、最後の返信13、周期完了16、21ms超の次周期開始間隔8件で、周期完了中央値18.561ms・最大22.792ms。追加計時があるためR14との差は純粋な速度改善・悪化とはみなさない。周期完了超過16件のうち13件は推論5ms以上、3件は世代1 GCと時刻が重なった。GCは第134・266・398周期で約3.06〜3.48ms続き、第134周期は返信後の記録処理、第266・398周期は後脚側ワーカーの送信前を遅らせた。前後バス別待ち・最後の返信後の処理・GCの重なりを[分類器](../tools/analyze_native_cycle_misses.py)へ追加した。

R16では安全判定や送信内容を変えず、500周期の間だけ自動GCを延期して同一起動・同じ0.8ms間隔／上限3で比較した。周期内GCイベントは0となり、終了後のGC有効状態・閾値を元へ戻したことを確認した。一方、周期完了超過はR15の16／500からR16の**21／500**へ増え、最後の返信超過は13→10、21ms超の次周期開始間隔は8→4件だった。R16の21件はすべて推論が5ms以上で、最初の18周期と第472〜474周期に集中した。周期完了中央値は18.589ms、最大21.974ms。GC延期だけでは20msを達成せず、既定へ採用しない。次は推論の事前ウォームアップ位置と回数を単独の選択式条件として比較する。これらはすべてSTOP代理・無駆動診断であり、学習済み目標を送る実出力周期の証明ではない。

R17はGCを通常設定に戻し、ウォームアップをワーカー起動・主スレッドCPU4固定の後に30回実行する選択式候補として同一起動で測った。選択式ウォームアップ後を第1周期の時刻基準とする修正と回帰テストを含む。500周期は完走し、CPU・affinityも元へ戻ったが、モデル呼出しが中央値14.690ms（R15は2.822ms）となり、周期完了の中央値30.440ms、最大33.654ms、**500／500周期すべてが20ms超過**した。この候補は採用しない。30回という回数とCPU固定後という順序を同時に変えたため、どちらが遅延の原因かはまだ分離できない。推論の尾部はPythonからTorchScriptへの1回の呼出しの内部で発生しており、外側だけのC++ラップではms単位の短縮を見込めない。次は保存入力だけでモデルの正確性と遅延分布を比較し、実機周期には合格した候補だけを戻す。

別ディレクトリで固定17バイト入力をC++解析する候補も作り、保存STOP 500周期・Type17 20周期、拒否30件、1バイト変異17,340件で既存Pythonの値・例外と一致した。Mac上のSTOP解析中央値は34.2→10.3µs、絶対短縮は約0.024msだった。この候補はJetson未測定で、20ms超過の主因を削る量にも足りないため実行経路には採用しない。[保存入力だけの実験と証跡](../runtime/experiments/native_snapshot_fastpath/README.md)を参照する。

## 実出力の通信設定を明示するV2

実出力プロファイルV2に`request_gap_us`と`request_window`を追加し、レビュー対象の設定ハッシュへ含めた。実出力・地上試験のCLI指定はプロファイルとの一致確認に限り、異なる指定をハードウェア準備前に拒否する。通常の要求と緊急STOPは同じ送信間隔を使う。V1は元の600µs／上限3と設定ハッシュを保持する。

新しい雛形・設定組立の既定値も600µs／上限3で未承認のままである。0.8msの診断結果や0.7msの一部成功から値を自動採用しない。今回のソフト統合282テストは通過した。別に31件のプロファイル照合テストも通過したが、その対象は282件と重なるため合計313件とは数えない。ソフト検証は実機の実出力28要求・荷重・50Hzの証拠ではない。

## 選択式V3の26要求化：ソフト検証

実出力プロファイルV3を明示した場合だけ、周期内のwatchdog設定`can_timeout`の巡回読取り2件を省き、取得14＋出力12＝26要求にする実装を追加した。既定V2は28要求のままである。全12軸の初期200ms watchdog設定・読戻しを維持し、音声終了後、最終姿勢・IMU再取得の前に全12軸を再照合する。全軸のfeedback監視、各バス1件の巡回電圧、STOP返信の検査は維持するが、周期中のwatchdog設定の書換えを巡回検出する範囲はV3ではなくなる。

cadenceと関係9ソースのSHAを設定レビューへ結び付け、V2のレビューをV3へ流用しない。未承認雛形・送信間隔600µs／上限3の既定は維持した。適用済みソースで208件の統合テストが通過し、実際の模擬送信数、電圧巡回、音声中の設定変化の拒否、監視異常時STOP、従来V1/V2の動作を確認した。以前の282件等と重なる範囲なので件数を合算しない。**V3の実機26要求周期は未測定で、ここまでのr6・r7の24要求STOP代理計測には反映していない。** 要求を減らした分の短縮量、全工程20ms・学習目標送信・荷重の合格証拠とはしない。[詳細な要求構成](active-loop-latency-budget-20260928.md)を参照する。

## 修正と残件

- 受信期限超過の表示を「全送信後の未返信ID」に修正。UID起動処理を直列化し、通常の周期要求と分離した。
- 6個の推論入力テンソルを再利用。183保存フレームをh=0/1で照合し、出力と内部状態の厳密一致を確認した。
- 一括ツールに`--request-window 1|2|3`と`--request-gap-us 600..5000`を追加。`can/compare/full/diagnostics`へ指定値を渡し、記録に残す。初回52テストに加え、スレッド事前起動を含むr7の対象73テストが通過した。
- スレッド事前起動と、0.8msを維持したtimer slackの100周期比較は完了。最後の返信まで全100周期20ms以内になったが、周期完了の超過2／100は推論と返信後のホスト処理を分けて調べる。0.7msはID9欠測のため現在の採用候補から外す。
- STOP代理の24要求と、既定V2の実出力28要求・選択式V3の26要求は別に評価する。26要求化はソフトのみの検証で、原点・IMU・通信断停止と新しいcadenceのレビュー後に、支持を残して学習目標を送る。

全工程の超過を受信期限や監視値の緩和で合格扱いにしない。生ログ・プログラム・CPU復元記録はMacの非公開スナップショットへ保存済み。r12までの公開向けの数値・原本ハッシュは[集計JSON](../evidence/hardware-native-cycle-20260928.json)にあり、UIDやモデル本体は含めていない。

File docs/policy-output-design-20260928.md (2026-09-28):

# 学習済みモデルの実出力試験：設定と証拠の分離

2026-09-28。これはオフラインで準備した実装設計です。この文書の作成・テストでは実機を駆動していません。

目標は、同じ短い試験のために校正や確認を最初から繰り返さず、検証済みの記録を再利用して学習モデルの目標値を実機へ送ることです。まず胴体の支持を残した、最大10秒の全12軸試験だけを扱います。支持台を抜く操作、自立、歩行はこのプロファイルの範囲に入りません。

## 同夜追加：現在姿勢から小さく動かす限定試験

明示選択のV3 `bounded_relative_supported_v1` は、絶対原点の精度を未知のまま記録し、現在姿勢からの相対変位を測る試験です。12軸の水準器原点・回転方向・新規角度記録・現物の各方向3°の経路確認を参照します。数値処理に使う2LSBの余裕を、水準器や機構の精度とは呼びません。

この方式では、生の学習目標をモデル範囲で確認し、現在姿勢へ混ぜた実送信目標を局所の現物範囲で確認します。変位は1°以内、実行3秒以下、混合率1%以下、Kp3・Kd0.15以下に限定します。9月28日夜の具体案は2秒・0.5%です。位置・速度・トルク・温度・鮮度・電圧監視と全軸STOPは維持します。

操作者のUSB切断試験省略指示は `command_loss_only_supported_trial` として別のハッシュ固定記録へ保存します。実際の全12軸指令途絶・無効化・終了STOP、個体とFWの一致を必要とし、USB切断は未試験のまま残します。絶対校正、動的速度・トルクの独立検証も完了と偽りません。箱支持を残し即時40V遮断を担当する人がいる限定試験であり、この設定・結果を支持台取り外しや歩行の承認に流用することはコードでも拒否します。以下の通常プロファイルの既定条件は変えません。

## 実装API

`runtime/singularitydog_hw/policy_live_profile.py` はファイルだけを読みます。SSH、CAN、I2C、torchのモデル読込みは行いません。

```python
from singularitydog_hw.policy_live_profile import load_profile, template

plan = template()  # 未解決事項とnullの校正/ゲイン/UID。実出力不可。
profile = load_profile('/private/path/profile.json', require_approved=True)
axis1 = profile['axes']['1']  # CAN ID順、文字列キー1..12
```

```bash
PYTHONPATH=runtime python3 -m singularitydog_hw.policy_live_profile \
  --write-template /private/path/profile.json
PYTHONPATH=runtime python3 -m singularitydog_hw.policy_live_profile \
  --check /private/path/profile.json --plan-only
```

`--plan-only` は未承認テンプレートの表示用です。承認済みファイルなら通常と同じ全検査を行います。`approved_for_supported_policy_output` をtrueに変えただけでは通りません。テンプレートにゲイン・原点・UIDを推測で埋めません。

返却値は独立したplain dictです。`axes[str(id)]` は次の値を持ちます。

| 項目 | 意味 |
|---|---|
| `uid`, `sign`, `offset_rad` | 校正ファイルと一致する個体・変換係数。`q_model = sign * raw + offset`。電源世代の360°分岐は実行側で別途結び付ける |
| `physical_lower_rad`, `physical_upper_rad` | 現物で確認したモデル座標の可動範囲。URDF範囲内に限定 |
| `uncertainty_rad` | 原点・姿勢合わせの不確かさ |
| `lower_rad`, `upper_rad` | ローダーが不確かさを内側へ差し引いた有効範囲。エンベロープへこの値を渡し、再度差し引かない |
| `kp`, `kd` | レビューされた試験ゲイン |
| `max_command_velocity_rad_s`, `max_command_acceleration_rad_s2` | 指令軌道の速度・加速度上限 |
| `max_tracking_error_rad`, `max_measured_velocity_rad_s` | 実測の追従差・速度監視 |
| `max_measured_torque_nm`, `max_estimated_pd_torque_nm` | 読取りトルクの監視と、指令前の推定PDトルク予算を別々に扱う |
| `max_temperature_c`, `max_displacement_from_start_rad` | 温度と開始姿勢からの移動範囲 |

ゲイン・トルク・温度の上限は、この短時間試験の実装範囲です。RS05や黄色い構造部材の保証限界ではありません。目標速度0・フィードフォワードトルク0でも、PD制御の合計トルクが0になるわけではありません。

## プロファイルに結び付けるファイル

`artifacts` の各値は `{ "path": "...", "sha256": "..." }`。相対パスはプロファイルの場所が基準です。次の6ファイルをすべて固定します。

1. `calibration`：既存 `MANUAL_NOMINAL_CANDIDATES_ONLY` スキーマ。12軸UID、符号、オフセットを照合。
2. `mount`：既存 `IMU_MOUNT_CANDIDATE_ONLY` スキーマ。右手系の回転行列を検査。
3. `bias`：既存 `GYRO_BIAS_CANDIDATE` スキーマ。独立したA/B記録を持つセンサ座標ジャイロ補正候補。
4. `model_manifest`：`native-policy-overnight-v1` の等価性検証済みファイル。実行側のローダーがABI、ライブラリ、モデル本体を再照合。
5. `pipeline_diagnostic`：取得・実推論・全12軸STOP送信を行った `native_pipeline_benchmark` のreport.json。
6. `hardware_review`：下記の現物確認をまとめた、明示的なレビュー記録。

既存の候補ファイルを「承認済み」に書き換えません。元の候補とその内容を確認したレビューを分け、どの結果を採用したか追跡します。`bundle_path` の3ファイルも既知の学習モデルのSHA256と照合します。

`profile['boot_id']`、`motor_power_epoch` は実行時の起動・40V電源世代です。再起動／電源再投入後の生角度を、前回の数値として扱いません。実行側は今回の12軸UIDとType17角度を取得し、個体一致と一意に決まる角度分岐を確認します。

## hardware_review の契約

これは測定データを自動承認するファイルではなく、測定を読んだ担当者の結論です。ファイルのハッシュとスキーマが合っても、現物の確認が正しかったことまではソフトで証明できません。

| キー | 必要な内容 |
|---|---|
| `schema`, `scope` | `singularitydog.supported-policy-hardware-review.v1` / `supported_characterization_only` |
| `review` | `reviewer`, タイムゾーン付き `reviewed_at`, `decision="APPROVED_SUPPORTED_CHARACTERIZATION"`, `rationale` |
| `assembly_id`, `uids_by_id` | 現在の組立識別子・12個のUID |
| `reviewed_settings_sha256` | `reviewed_settings_sha256(profile)` で得る値。ゲイン・限界値・原点・移動量・推論重みを含む。数値を変えると再レビューが必要 |
| `artifact_sha256` | `hardware_review` 自体を除く5入力のSHA256 |
| `source_captures` | 元の実機記録JSONへのpath/SHA256のリスト。相対パスはレビュー記録の場所が基準。内容を担当者が確認する |
| `angles[ID]` | 原点・符号、現物範囲と干渉、電源投入時分岐方法を確認した3つの真偽値と、プロファイルと同じsign/offset/範囲/不確かさ |
| `imu` | 固定取付方向、鼻上げ・左上げ・左旋回の方向、別の静止記録でジャイロ補正、重力方向を確認。重力方向最大誤差・残留ジャイロ・静止ノルム範囲と偏差の説明を記録 |
| `type2_dynamic[ID]` | 実際に動かした記録で出力軸角度、速度換算と符号、トルクの解釈を確認。固定範囲は位置±12.57rad、速度±50rad/s、トルク±5.5Nm |
| `device_watchdog[ID]` | 実際の指令途絶試験とUSB切断試験、途絶後に無効化した確認、設定200ms、最大実測停止時間、FW版数、motor_model=RS05 |
| `mode0_readback_required_before_enable` | true。過去の確認で代用せず、毎回有効化前にMode0を読み返す |
| `timing_budget_rationale` | 診断結果に対して採用する最大周期・連続超過数の理由 |

フィールドの正確な名前はモジュールの `_hardware()` が契約です。単体テストの合成レビューを実機のレビューとして使うことはできません。テストでは学習モデルの固定ハッシュ自体を明示的に差し替えてあり、製品設定では読み込めません。

静止時のType2/Type17比較は、位置の一致を見るのに役立ちますが、速度換算の動的妥当性は示しません。従来の角度差・静止時ノイズの記録だけでは `type2_dynamic` を承認しません。

IMUの約9%の静止ノルム差は、単一姿勢から加速度バイアス／スケールを推定して帳尻を合わせません。重力方向の複数姿勢照合と生ノルム範囲を確認し、正規化した重力方向をこの試験に使えるかを明示的に評価します。絶対yawは静止姿勢からは得られません。

## 20msと短い実出力の関係

実出力前に、同じモデル・校正・IMUで最低20周期の全工程無出力診断を確認します。読み取りだけの速度や合成入力の推論速度では代用しません。

目標周期は20ms固定です。支持台上の原因切り分けでは、レビューを付けて `hard_cycle_ms` を20〜60ms、`max_consecutive_20ms_misses` を0〜3にできます。テンプレートは20ms／0回です。周期超過を無視する設定や、無制限の待ちにはできません。入力の鮮度は最大周期以下です。別の制約である入力間隔 `max_sample_gap_ms` にはOSのスケジューリング差のため最大周期＋1msまでを許し、テンプレートは21msにします。この1msは入力の古さや処理時間に加える余裕ではありません。

20ms超過は、実処理時間または最古入力の取得開始から最終ホスト送信までの時間で数えます。スリープ復帰の微小な遅れをこの計算に混ぜず、復帰間隔は別に記録し1msの診断許容を設けます。開始間隔が極端に空いた記録や、重複周期、時刻の逆転は拒否します。要約の中央値を信用せず、元の単調時計タイムスタンプで再計算します。

ここで得られるのはSTOPを送った診断の実績です。実際のMIT指令に切り替えたときの20ms達成とは区別し、`actual_policy_output_20ms_verified` はfalseのままです。最初の実出力試験で同じ区間を改めて記録します。

## 通信断時の停止

USBが抜けた後、ホストからSTOPを送ってもモーターへ届きません。PythonのfinallyやC++の例外処理は、送信経路が残っているときの停止処理です。SSH切断・プロセス停止・ホスト電源断を、ホストのSTOPだけで保証しません。

このため、12台それぞれについて**設定値を読み返しただけでなく、指令が途絶したとき実際に無効化すること**が必要です。USB切断でも別プロセスの送信が続いていないことを確認します。自動報告だけでタイムアウトが更新される実装なら、想定したwatchdogになっていないので採用できません。実装は従来と同じ4000tick＝200msに固定し、別の値で行った試験を証拠として流用しません。

watchdogは無効化までの最大移動量や、脱力後の機体支持を保証しません。最初の実出力試験では支持を外さず、即時40V遮断の担当と経路を維持します。身体での支持だけに依存した状態でソフト開発の待ち時間を作りません。

## 効率化する実行順序

1. オフラインでプロファイル・モデル・証拠の全照合を済ませる。パス違い／不足フラグはこの段階で解消する。
2. 実機で一度だけ支持・接触なし・即時Offを確認し、12台を一括で新しい起動／電源世代へ結び付ける。
3. 同じ実行プロセスでモード・watchdogの読返し、初期入力の範囲を確認する。
4. 日本語の開始音声後、現在位置からゲインを滑らかに上げ、モデル出力の重みを増やす。各軸の速度・加速度・開始位置からの変位を制限する。
5. 正常終了は、加速度制約で減速する時間とゲインを下げる時間をあらかじめ最大10秒内へ予約する。硬い異常条件では通常の滑らかな停止より即停止を優先する。
6. 最後のSTOP返信と実物の様子をまとめて確認し、成功した軸・項目を再試験の対象から除く。

これで毎回の確認の重複を減らせます。現在の未解決条件を削除して成功扱いにする効率化は行いません。

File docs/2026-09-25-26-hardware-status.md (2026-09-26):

# 実機検証の結果と残件 — 2026-09-25〜26

## 9月25日

RS05の12軸すべてを公式FW `0.5.0.13` へ更新した。更新後に全軸のUID・版数・STOP返信（mode 0／fault 0）を照合し、最後の電流読取りは全軸0 Aだった。更新作業中はモーター有効化と動作目標の送信を行っていない。更新後も6軸の自動報告開始は安定せず、失敗後の解除とSTOPは再検証した。

実入力取得・入力組立て・実推論・STOP代理送信の無出力診断を改善した。最古入力の取得開始から最後のホストwrite復帰まで、3回の中央値は `20.063 ms`、最大 `20.136 ms`、最良の1回は `19.785 ms` だった。最後の返信までの中央値は `22.791 ms`。送ったのは学習済み目標角ではなくSTOPで、連続50 Hz制御や全周期20 ms以内は未達である。

## 9月26日

MAX98357Aを使うI2S2音声案内を実機スピーカーで確認し、「テスト開始します」を明瞭に聞き取れた。音声再生に失敗すると音声付き試験を起動しない構成とした。

起動ID `1743e35c-3b44-4fa6-88a9-855b5b62e214` で12軸の無動作記録を取り直した。最初の記録はSTOP順序が保持パッケージの監査条件に合わず、全軸STOP先行で再取得した記録を使用した。無効化の保持プリフライトと前脚付け根10°プリフライトは、ともにモーター有効化・動作用ゲインなしで完了した。[現起動の記録](stance-current-verification-1743-20260926.md)にログとハッシュをまとめた。

有効化した12軸の現在位置保持は前後各100周期を完走し、全12軸STOP、ポート閉鎖、ロック解放を確認した。操作者から実機の異常は報告されていない。続く右前付け根ID3を+10°、左前付け根ID6を−10°へ向ける試験は、最初の周期中に `Stale feedback` で中断した。パケットゲートは前後各4/6軸の最初の動作用送信と完了周期0を記録し、全12軸STOPを確認した。操作者は動き・異常・接触を見ていない。**10°軌道は未完了**である。

Enable後のゼロゲインパケットを扱うゲートと、最初の動作周期だけ返信鮮度の許容を125 ms（通常周期は100 msのまま）とする修正をローカルで検証した。`runtime/tests` の全1195件を実行し、1件スキップ、失敗0件だった。後者は実機では再試験していない。次の判定には同一起動の根拠を確認した上で10°軌道を完走し、追従と実物の隙間を観察する必要がある。固定立位、荷重移行、学習済みモデル出力、歩行、連続20 ms制御は確認していない。

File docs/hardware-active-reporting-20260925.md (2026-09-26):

# RS05自動報告の実機検証 — 2026-09-25

> このページはFW **0.5.0.9**での検証履歴です。その後、全12台を0.5.0.13へ更新しました。[更新後の再検証と対策](hardware-post-firmware-remediation-20260925.md)では、単台・3台の解除成功、6台の開始欠測、終了処理の修正を記録しています。

**自動報告は単独では成功しましたが、3台でも解除の失敗が再現しました。全12台のFWは0.5.0.9です。** 最新の6台比較では開始応答も1台欠け、測定開始前に中断しました。前6台を解除した後、最後に全12台の個体照合・STOP返信・100ms静穏・ポート閉鎖を確認しました。後6台・前後12台の自動報告はまだ試していません。

**その後の送信側の検証：** STOPの2フレームまとめ書込みは完走、3フレームは返信欠落で中断しました。その後の前脚側通信停止は、USB抜き差しと40VのOff／On後に復旧し、全12台を再確認しています。[まとめ送信の結果と復旧記録](hardware-stop-batch-20260925.md)

目的は、毎周期の位置・速度の問合せを減らし、20ms制御へ向けた受信方式を検証することです。全試験で励磁・駆動指令・周期設定の書換えは行っていません。

## 条件と結果

| 条件 | 結果 | 設定・終了状態 |
|---|---|---|
| r1：周期値を厳密に検査 | UID一致。`0x7026`が生値0で、資料上の1以上に該当せず中断 | 個体識別と周期読取りだけ。設定変更・STOP送信前に閉鎖 |
| r2：周期値を変更せず観察 | 電圧39.65V。ON後にType2が1件、その後Type24が1件。型の変化を検出して測定開始前に中断 | Type18なし。OFF、100ms静穏、別区間のSTOP返信、ポート閉鎖・共通ロック解放を確認 |
| r3：開始／解除のType2を分離、ID1・1秒 | Type24を100件。間隔中央値10.009ms、最大10.297ms | 完走。周期設定変更なし、解除・STOP返信・閉鎖を確認 |
| r3：同条件、ID1・10秒 | Type24を1,000件。間隔中央値10.010ms、最大10.611ms。20ms超の空白なし | 完走。周期設定変更なし、解除・STOP返信・閉鎖を確認 |
| r3：同条件、ID1・60秒 | Type24を5,995件。間隔中央値10.010ms、最大12.126ms。20ms超の空白なし | 完走。解除・STOP返信・閉鎖を確認 |
| r3：前6台・10秒 | 全IDで各999〜1,000件、計5,997件。全ID中の最大間隔12.304ms | 不成立。約1ms間隔のOFFでID1・2だけ停止、ID3〜6の報告が残った |
| r4：前6台・1秒、OFFの間隔を変更 | 各99〜100件、計599件。最大間隔12.141ms | 不成立。OFFを約21.66〜22.05ms間隔にしてもID2・3の報告が残った |
| r4：対象を限定した復旧と最終確認 | 残ったID2・3を個別に解除。その後、前6台すべてでOFF後のType2・100ms静穏・UID再照合・STOP返信を確認 | 復旧完了。ポート閉鎖・共通／ポート排他解放。再有効化なし |
| r5：全12台の版数確認 | 全台の版数バイト列`00 05 00 09`（0.5.0.9）。周期生値は全台0、電圧38.04〜39.33V | 報告ON／周期変更なし。識別・STOP・版数・静穏を確認 |
| r5：ID3単独・1秒 | 100件。間隔中央値10.010ms、最大10.598ms | 完走。OFF後のType24は0件、別区間STOPを確認 |
| r5：ID1・2・3、ID3から解除・1秒 | 各100件、計300件。最大10.290ms | 不成立。最初のOFF対象ID3とID1で報告が継続。独立の解除処理で両台を復旧 |
| r5：前6台、ID3から解除する条件 | ID1〜5の開始時Type2を観測。ID6の開始応答がなく、測定窓へ入る前に中断 | 解除後もID3のType24が継続。独立の前6台解除で復旧。1秒／6台の性能値として集計しない |
| r5：最終の全12台確認 | 全UID一致・全STOPがmode0／fault0・前後各100ms静穏 | 報告ONなし。両ポート閉鎖・排他解放を確認 |

生値0は未解明です。「0＝10ms」「非対応」「無効」のいずれとも断定していません。r2はType24が1件返った時点で中断しましたが、r3では明示した応答列を分離し、ID1の10秒間の継続を確認しました。実測は約10msですが、生値0の一般的な意味を確定したものではありません。

r3では、実機で観測した開始直後のType2を1件だけ分離し、その後のType24を周期報告として検証しました。解除時のType2も別記録にしています。これらをSTOPへの応答や設定適用の証明として扱いません。

各件数は計測窓に完全に入ったフレームだけです。資料の公称10msから計算した6,000件と60秒の5,995件との差だけで、物理的な欠落件数とは判定できません。実測中央値は10.010msで、境界を跨ぐ受信も別記録しています。

最初の復旧では、ID2のOFF直後のType2を確認できず不成立にしました。ID2を独立に確認した後、r4の再試験へ進んでいます。失敗した実行の記録は残し、後の復旧成功で上書きしていません。

r5は対象ID3を固定し、他の報告台数を変えました。3台条件ではID3を最初に解除したため、その時点でID1・2はまだ報告中でした。ID3の報告はOFF後も126件・約1.252秒続いており、単にType2返信を取り逃しただけではありません。6台条件でもID3の報告がOFF後約2.122秒続きました。ただし各条件1回の比較であり、台数と失敗率の関係や根本原因を確定したものではありません。

## 判明した課題と次の切り分け

1. **受信性能と解除の信頼性を分ける。** 6台受信は約10msですが、20ms間隔の送信だけでは解除問題を解消できませんでした。ホストの17バイト書込み完了は、CAN線上の送信完了やQDDの適用を証明しません。
2. **アダプター側とQDD側の競合を区別する。** 同じID3で1台成功・3台解除失敗・6台開始失敗を記録しました。次の切り分けはCAN線上の受動観測、またはFW変更前後の同条件比較です。ホストログだけでは、OFFがCANへ出なかったのか、QDDで処理されなかったのかは判別できません。
3. **FW更新の比較を準備する。** 現物は全台0.5.0.9でした。公式の累積履歴はRS05の0.5.0.13で自動報告と返信の偶発競合を改善したと記載し、確認した公開最新版は0.5.0.14です。ただし今回と同じ不具合かは未確定です。Windows環境がないため更新方法の整備が残っており、今回ファームウェアは書き換えていません。[公式リリース資料](https://github.com/RobStride/Product_Information/releases/download/V26.05.19/default.pdf)・[公式リリース一覧](https://github.com/RobStride/Product_Information/releases)
4. **解除が成立してから後6台・12台へ進む。** 自動報告を制御へ採用する前に、周期報告中の通常コマンドと解除の両方を評価します。

## 20msの判定

この検証はCANの自動報告だけです。IMU取得・入力組立・推論・指令送信を含む全工程20msは、まだ達成確認できていません。直近の統合代理測定は、最古入力の取得開始から最終ホスト送信まで中央値37.780ms、最大39.089msでした。

自動報告の最新値を保持する方式なら、毎周期のQDD問合せ待ちを減らせます。ただし既存3回の統合測定は、入力取得完了後だけでも22.490〜24.606msです。入力準備・推論周辺処理・送信の短縮も必要です。内部サンプル時刻がないため、次の統合測定でもホストで観測した入力の古さと処理周期を別に記録します。

## 入力組立ての改善

生フレームの再解析・コピーを整理し、検査済みの値と証跡を変更不可の入力にまとめる実装を追加しました。時刻・ID・mode／fault・古さ・数値範囲の検査、既存の推論側の校正／出力範囲検査は維持しています。

Jetson（aarch64／Python3.12.3）で9月24日の保存データ3件を各100回再生し、旧実装・保存済み結果と全項目が一致しました。同じ実行環境での中央値比較です。

| 保存データ | 旧・組立て | 新・準備＋組立て | 短縮率 |
|---|---:|---:|---:|
| 01 | 1.546ms | 1.330ms | 14.0% |
| 02 | 1.546ms | 1.326ms | 14.2% |
| 03 | 1.546ms | 1.324ms | 14.3% |

準備済みの入力からの組立てだけなら約0.056msですが、新しい入力の準備に約1.27msかかります。この費用も含めて短縮率を算出しました。保存データのCPU再生であり、新しいセンサー値の取得・推論・送信は含みません。以前の実入力統合試験の3.671msとは測定条件が異なるため、そこからの差を今回の改善量とは扱いません。

自動報告の課題と並行して、Type2返信を使うSTOPまとめ書込みを比較しました。2フレーム条件は全6台の返信まで21.715ms、3フレーム条件は欠測で中断しています。[詳細な結果](hardware-stop-batch-20260925.md)を踏まえ、次は従来の1フレームずつ送る方式の処理・待ち時間を改善します。自動報告の採用は別に判定します。

## ソフトウェア検証

実装は型・ID・mode／fault・受信期限・途中の型変更を検査し、ON/OFF直後の観測を周期集計から除外します。途中の送信失敗時に追加送信を行わず、受信待機も失敗した場合は残りのOFFを未実施として記録します。

最終ローカル全819テスト、Jetson上の対象148テストが成功しました。分割・連結受信、開始／解除時の余分な返信、欠落、遅延、部分書込み、閉鎖失敗時のロック保持を含みます。今回、解除後の部分フレームが残っていたら次の問い合わせを禁止する境界検査も追加しました。テストの成功は上記の実機課題を解消した意味ではありません。

生フレーム、設定前の値、終了処理、ソースのハッシュは非公開の実験記録へ保存しています。個体UIDを含むため公開文書には載せません。

- [有限検証ツールの説明](../runtime/ACTIVE_REPORTING.md)
- [公開集計JSON](../evidence/hardware-active-reporting-20260925.json)
- [今日の検証計画](hardware-test-plan-20260925.md)
- [直近の統合測定](hardware-summary-20260924.md)

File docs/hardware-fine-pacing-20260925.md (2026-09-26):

# 送信間隔0.8／0.7／0.6msの有限比較 — 2026-09-25

**未返信上限を各バス3件に固定した通信単独の比較では、0.6ms条件が取得中央値7.723ms・最大8.095msで、3回とも欠測なく完了した。** 同じ比較の0.8ms条件から中央値0.977ms短縮した。IMU・推論・後段送信を含む全工程20msの達成を示す測定ではない。

[機械可読な監査結果](../evidence/hardware-fine-pacing-20260925.json) · [前回の通信・統合結果](hardware-pacing-optimization-20260925.md)

前後6台ずつを並列に取得し、全12台のUID確認後、全0のType4停止命令へ返るType2を各条件3周期測定した。各起動は48個の個別17バイトwrite（UID12・STOP36）と48返信。CPUは既存729,600〜1,497,600kHzの上下限内で一時的にperformance、受信方式・プログラム・イベント記録方式は3条件で同じ。モーター有効化・目標値送信・自動再試行は行っていない。

| 最小間隔 ms | 取得中央値 ms | 取得最大 ms | ホストwrite区間中央値 ms | 同最大 ms | 結果 |
|---:|---:|---:|---:|---:|---|
| 0.8 | 8.700 | 8.792 | 5.938 | 6.032 | 3回完了・48送信／48返信 |
| 0.7 | 8.412 | 8.625 | 5.661 | 5.784 | 3回完了・48送信／48返信 |
| 0.6 | 7.723 | 8.095 | 5.015 | 5.331 | 3回完了・48送信／48返信 |

取得時間は最初のSTOP write開始から全12台の最後の返信まで。ホストwrite区間は最初のwrite開始から最後のwrite復帰までで、CAN線上の送信完了とは異なる。0.6ms条件のホストwrite区間は0.8msより中央値0.923ms短い。0.6ms条件の実際のwrite復帰→次write開始は、前バス中央値0.757ms・最短0.729ms、後バス中央値0.732ms・最短0.722msだった。

保存した生バイト・フレーム・返信対応・時刻を既存の検証関数で再照合し、9周期の時間を再計算した。全条件で送信間隔違反なし、実際の最大未返信は各バス3件、STOP返信108件はすべてmode0／fault0。未返信・残留バイトなし、ワーカー・ポート・起動確認FDの終了と排他解放も確認した。CPUのschedutil復元は親処理・独立watchdog・外部読取りの3記録で一致し、周波数上下限も不変だった。

監督処理の最終JSONには前回の条件ラベル（上限3／4／2件、間隔すべて0.8ms）が残っていた。これは記録上の不整合として原本を保持し、証拠JSONにも明記した。実際の上限3件固定・間隔0.8／0.7／0.6msは、ハッシュ固定の子処理、各回の実行計画・結果、照合済み生ログで確認している。実行やCPU復元の失敗として扱うものではない。

各条件3周期の順次比較であり、長時間安定性やp99の保証には使わない。以前の0.5ms・上限2件の返信欠落は別条件の失敗として残る。今回の0.6msを統合工程へ反映した場合の効果は、実入力・実推論を含む別の測定が必要である。

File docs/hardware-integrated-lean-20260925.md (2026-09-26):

# lean・所有権受渡し・0.6ms送信間隔の統合結果 — 2026-09-25

**実入力取得→lean推論→最後のSTOP代理write復帰は中央値22.283ms、最大23.193msとなった。3回とも完了したが、20msには未達である。** 前回の中央値24.568ms・最大25.037msからそれぞれ2.285ms・1.844ms短縮した。今回の残りは中央値2.283ms、最大3.193ms。最後の返信まで含めると中央値25.123ms・最大26.035msとなる。

[計時・生ログ監査・ハッシュ](../evidence/hardware-integrated-lean-20260925.json) · [前回の統合結果](hardware-pacing-optimization-20260925.md) · [通信単独の0.6ms比較](hardware-fine-pacing-20260925.md) · [凍結候補の比較](hardware-native-policy-freeze-20260925.md)

## 変更と実測

前回の統合コードを基準に、モデルを既存の非凍結leanへ切替え、組立て済みsnapshotを一度だけ消費する所有権受渡しにし、各バスの最小送信間隔を0.8→0.6msへ変更した。未返信上限は3件のまま。変更したruntimeファイルは2つで、校正値・ネイティブ投影ライブラリー・その他runtimeのバイト列は同じである。入力の有限値・範囲・鮮度・前回sourceとの整合性・全snapshotハッシュ・出力検査を保持した。凍結版は今回使っていない。

| 工程 | 前回中央値／最大 ms | 今回中央値／最大 ms |
|---|---:|---:|
| QDD・IMU並列取得 | 9.073／10.119 | 8.120／8.580 |
| 新しい入力の組立て | 1.643／1.702 | 1.687／1.705 |
| 入力検査・実推論・出力変換 | 6.023／6.851 | 6.547／7.256 |
| 最初〜最後のSTOP代理write | 6.399／6.619 | 5.329／5.661 |
| **最古入力開始→最後のwrite復帰** | **24.568／25.037** | **22.283／23.193** |
| 最古入力開始→最後の返信 | 27.434／27.950 | 25.123／26.035 |

各回の全工程は21.362041／23.192745／22.283121ms。モデル呼出しは3.729539／5.992735／5.302829msで、ばらつきが残る。observer全体の中央値は前回より増えており、全工程短縮をleanだけの効果とは説明しない。3要因を同時に変更し、前回とは別の入力・別の試行で測定した比較である。工程別の中央値・最大値は足し合わせない。

所有権受渡しの区間は0.013792／0.013504／0.013376ms。前回のsnapshot再コピー中央値0.175msを省く変更であり、「コピーが0.013msになった」という意味ではない。元イベントの有界コピー・再検査・出典ハッシュを含む新規入力組立ては今回も中央値1.687msかかる。observer内の出典ハッシュ・整形は中央値0.437ms、テンソル生成は0.216msだった。

## 完了と独立監査

各回は全12台の識別確認、入力STOP12送信、推論1回、代理STOP12送信で36個の個別17バイトwriteを行い、36返信を受けた。3回合計108送信／108返信、うちSTOPの72返信はすべてmode0／fault0だった。最小間隔・未返信上限、生受信バイトとフレーム、返信対応と時刻、snapshot digest、全工程の因果順序を独立に照合した。全13種類の時間差も保存時刻から再計算し、監査JSONと一致した。

全回で欠測・残留バイトなし。IMU設定復元、ポートとworker・起動確認FDの終了、排他解放を確認した。CPUは既存729,600〜1,497,600kHzの上下限内で一時的にperformanceとし、親処理・独立watchdog・外部読取りの3記録でschedutilへの復元が一致した。

計時は最古入力のホスト取得開始から最後のホストwrite復帰までで、モデルload・10回warmup・識別要求は含まない。ホストwrite復帰はCAN線上の送信完了ではない。実モデルを呼び出しているが、後段は全0の停止命令であり、学習済み目標やモーター有効化は送っていない。単発3回の成功は連続50Hzや通常駆動の実証ではない。

## 準備時の試験修正と残る課題

先行する監督bundle r4は、ローカルとJetsonのPython版をまたいだAST文字列ハッシュ比較の試験で失敗し、実機計測には進まなかった。r5では固定した基準ソースと候補を同じPythonで構文解析して比較する移植可能な試験へ変更した。監督処理とlauncherの関数・クラスASTはr4から同一で、復元・実行処理を変更して通したものではない。準備時のローカル試験は監督側61件成功、統合payload108件中107件成功・既存の非同梱記録1件skip。今回の完了判定は準備時statusではなく、実行後の記録と生ログに基づく。

20msへの不足はまだ2〜3msある。次は残る入力準備とモデル呼出しの費用・ばらつきを分けて測る。モデル単体や保存入力の再生値を今回の全工程から差し引かず、同じ統合条件で確かめる。凍結leanは別のobserver再生で最大遅延が悪化したため、今回の統合版には採用していない。

## 今回の保存入力で追加した切り分け

今回の3回分をそのまま保存し、各入力について元モデル／leanを別々の新しいプロセスで再生した。各プロセスは統合版と同じ10回warmup後に初回を計時し、その後も毎回resetして10回測定する。計66回で保存された全出力・観測値・provenanceが一致し、元モデルとleanの全parameter・buffer・observer内部状態も一致した。時刻や入力値は書き換えていない。

| 保存入力 | 統合時leanモデル呼出し ms | 単独再生の初回 ms | 単独再生の後続10回中央値／最大 ms |
|---|---:|---:|---:|
| 1 | 3.730 | 3.066 | 3.053／3.194 |
| 2 | 5.993 | 3.440 | 3.133／3.478 |
| 3 | 5.303 | 3.418 | 3.164／3.322 |

同じ姿勢入力でも単独再生では統合時の約6msは再現しなかった。次の候補は、通信・IMUワーカーとの実行競合、CPUの実行コア移動、warmup後の初回経路を分ける比較である。ただし単独再生はschedutil、統合測定は一時performanceであり、周波数・キャッシュ・ワーカーの有無も違う。この差だけで競合が原因とは確定せず、表の短縮幅を全工程から差し引かない。

初版再生ツールは最初の推論後、内部状態の文字列／tuple混在キーを並べ替える記録処理で失敗した。第2版は型を保持した並べ替えだけを修正し、失敗記録を残して別ディレクトリーへ再実行した。モーター通信や制御コードへの変更はない。

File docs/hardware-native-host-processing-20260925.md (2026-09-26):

# 20msに向けたホスト処理のC/C++化 — 2026-09-25

**返信検査もC++化し、取得開始→最後のホスト送信で19.785msを1回記録した。3回の中央値20.063ms・最大20.136msで、全回20ms未満には未達。** この計測は実推論後に停止命令を送る無出力診断である。

| 最新の区間（r10 / r8、3回） | 中央値 | 最大 |
|---|---:|---:|
| 並列取得 | 8.384ms | 8.408ms |
| 入力組立て | 1.200ms | 1.217ms |
| 入力検査・実推論・結果変換 | 4.426ms | 4.506ms |
| 最初〜最後のホスト送信 | 5.548ms | 5.679ms |
| **最古入力の取得開始→最後のホスト送信** | **20.063ms** | **20.136ms** |
| 最古入力の取得開始→最後の返信 | 22.791ms | 22.830ms |

3回のホスト送信終了までの値は **20.135871 / 20.063117 / 19.785404ms**。
すべて36送信・36返信（12識別＋24個のゼロSTOP）、生フレーム・時刻・ファイルハッシュを独立照合した。
起動後の設定確認、親・watchdog・外部読取りの3通りでCPU設定復元も確認済み。
モーター有効化、学習済み目標値の送信、連続50Hz制御は実行していない。
ホストwrite復帰はCAN線上の送信完了とは異なり、返信を含めた区間は20msを超えている。

入力組立ての中央値は前版1.539→1.200ms。全工程中央値は20.238→20.063ms。
最大値の改善には推論のばらつきの変化も含むため、すべてをC++化の効果に帰属しない。
以下は実装・検証の経緯と変更前の測定記録。

[直近の全工程実測](hardware-warmup-order-20260925.md) · [今回の検証記録](../evidence/hardware-native-host-processing-20260925.json) · [再現用ソース](../runtime/experiments/native_diagnostic_r1/README.md)

| 変更 | 減らす処理 | 維持する検査 |
|---|---|---|
| 受信・ログ・入力組立てのコピーをC化 | Pythonで辞書・配列を再帰走査する費用 | 型、有限値、循環参照、深さ・要素数・バイト数の上限、書換えから独立したコピー |
| 起動確認の短い読取りをC++化 | 短いOS読取りの前後で生じるPythonスレッド切替 | 所有ロック、毎回の新しい読取り、同じ確認箇所、終了・FD再利用との排他 |

コピーは値・型・証拠ハッシュを照合した。起動確認は値をキャッシュせず、各スレッドが所有するprocfsのFDを毎回読む。繰り返すEINTRは8回でエラーとして終了する。80バイトの読取り上限はシステムコール時間の保証ではなく、既存の外部watchdogを残す。

通信の最小間隔0.6ms、未返信上限3件、モデル、校正、入力時刻、warmup順序を保持した。モーターを有効化する処理も、学習済み目標値を送る処理も追加していない。ネイティブのソースと実行バイナリのハッシュは、実行前に監督処理が確認する。

| Jetson上の機能検証 | 結果 |
|---|---:|
| ネイティブコピー | 16テスト成功・23,668件の照合成功 |
| 既存処理へコピーのみ組込み | 114成功・既存記録がない2件skip |
| ネイティブ起動確認 | 20テスト成功 |
| 2候補を組み込んだ統合処理 | 117成功・既存記録がない2件skip |
| 統合処理の監督・復元・結果検査 | 66テスト成功 |

JetsonのCPython 3.12.3、GCC/G++ 13.3でビルドした。足りなかった開発ヘッダーは専用フォルダーへ展開し、OSのPythonを更新・置換していない。Macでの速度比較はJetsonの効果として扱わない。

保存入力の交互比較はCPU governorをperformance、周波数上下限729600〜1497600kHzとして、別プロセス2回で実施した。各比較は15標本・20反復。2回の入力組立てのCPU時間中央値は、Pythonの1.234／1.233msからネイティブの0.907／0.908msへ減少した。一般のイベントコピーは12.274／12.295µsから2.118／2.111µsへ減少。値・型・証拠ハッシュの一致を確認済み。

起動確認は別プロセスで計30,000回測定し、2スレッド・各1,000確認と固定イベントコピーを行う合成負荷の経過時間中央値が120.184→116.627msだった。これは1制御周期の短縮量ではない。親・独立watchdog・外部読取りでCPU governorのschedutil復元を確認し、モーター・IMUにはアクセスしていない。

返信検査のC++化前（r9 / r7）の3回測定では、全工程は **20.238 / 20.100 / 21.428ms**。最古の入力取得開始から最後のホストwrite復帰までを生の時刻から再計算した。最後の返信までの中央値は22.931ms・最大24.271ms。各回36送信・36返信とCPU設定の復元を確認した。

| 区間 | 中央値 | 最大 |
|---|---:|---:|
| 並列取得 | 8.274ms | 8.338ms |
| 入力組立て | 1.539ms | 1.630ms |
| 検査・推論・結果変換 | 4.500ms | 6.159ms |
| 最初〜最後のホスト送信 | 5.306ms | 5.626ms |
| 最古入力の取得開始→最後のホスト送信 | **20.238ms** | **21.428ms** |

3回目の遅れは主に推論で、モデル呼出しが3.25〜3.29msから4.92msへ増えた。送信区間は3回目が最短だった。各区間の最大値は別の試行で生じるため、表の最大値を加算しない。

次は返信内容の検査をC++化し、保存入力で判定・値・証拠ハッシュを照合する。推論のばらつきも保存入力で切り分ける。停止命令を送る診断であり、ホストwrite復帰はCAN線上の送信完了とは異なる。この結果だけで学習済みモデルによる連続50Hz駆動を合格にはしない。

### 次の実入力計測へ向けた準備

返信検査のC++版は、Jetsonで67,568件の差分比較と追加549件の独立確認に通った。
保存入力のCPU時間中央値は1.212→0.658ms（schedutil条件）。組込み版118テスト成功、
過去記録不足2件skip、監督・復元処理66件成功。新しい実入力の全工程を3回計測済み。最新結果は冒頭の表を参照。

推論を実行する全プロセススレッドのCPU固定も、保存入力で3回×90標本比較した。
自由配置のモデル時間中央値3.04〜3.17msに対して、1コア固定は14.74〜15.03msへ悪化した。
全出力・内部状態は一致し、affinityとCPU governorを復元した。この固定案は採用しない。

### 残る改善の優先順位

1. 推論入力のテンソル生成（直近で約0.15ms）を保存入力で比較する。再利用する場合も、入力やモデル内部状態の別名参照、型、出力・内部状態・異常入力の拒否が変わらないことを確認する。
2. JSON証跡生成と入力準備をプロファイルする。証跡や入力時刻を省略・改変して短縮扱いにはしない。
3. 改善を確認した候補のみ新しい実入力で反復し、全回20ms未満になるかと、返信までの区間を別々に評価する。

Type2デコード単独は保存入力のJetson CPU計測で中央値5.415µs/回だった。
12回分でも約65µsが元の処理全体の費用であり、この処理だけで0.15ms短縮する案は見送った。
通信間隔0.6ms・未返信上限3・1回17バイトの書込みは維持する。

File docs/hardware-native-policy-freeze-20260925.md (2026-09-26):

# 凍結モデルのCPU比較 — 2026-09-25

**凍結leanは同値検証を通過し、入力検査を含むobserver中央値は4.525→4.091msへ短縮した。一方、最大値は4.837→6.610msへ悪化したため、次の統合比較r7には凍結していないleanを使う。** 凍結版はCPU再生用の候補として保持し、実入力取得・送信を伴う統合工程にはまだ使っていない。

[生計時値・監査結果・ハッシュ](../evidence/hardware-native-policy-freeze-20260925.json) · [lean候補の先行検証](hardware-native-policy-lean-20260925.md) · [前回のobserver比較](hardware-observer-lean-replay-20260925.md)

## 凍結と同値検証

`torch.jit.freeze`を段階的に適用し、数値最適化は無効のまま、reset・controllerの公開メソッド・変化する状態を保持した。保存・再読込みでモデル間の状態共有を切り、全11項目の可変状態が独立した領域にあることも確認した。actorの8個の重み・biasテンソルは凍結グラフの定数とビット単位で一致した。controllerの削除された11属性は初期化後に書き換えないことを固定ソースの監査で確認した。

元モデル、lean、凍結元モデル、凍結lean、凍結2種の再読込み版の計6モデルを比較した。

- 変化する合成入力240ステップで、12目標値・74観測値・12actor値・可変状態とresetを完全照合。記録された最大絶対差はすべて0。
- NaN／Inf／形状違い、重力・コマンド・h等の26ケースで拒否理由と例外後の状態が一致。
- controllerの診断辞書を16ステップで全項目照合し、完全一致。入力を変更しないことも確認。

これは指定した系列と異常ケースでの結果であり、全入力空間の証明ではない。重みの同値照合と、不変属性を書き換えないことのソース監査は区別している。

## forward単独の同じ試行内の比較

Jetsonの`torch 2.14.0+cpu`、intraop／interop各1スレッドで測定した。保存入力を使用し、warmup20回後のCPU forwardだけを計時。observer・入力テンソル作成・reset・取得・送信は含まない。下表は同じ実行内の比較で、p95はnearest-rank方式。全生配列から中央値・p95・最大値を再計算して一致を確認した。

| 条件 | モデル | 回数 | 中央値 ms | p95 ms | 最大 ms |
|---|---|---:|---:|---:|---:|
| 毎回reset後 | 元モデル | 60 | 3.271 | 3.563 | 3.593 |
| 毎回reset後 | lean | 60 | 2.841 | 3.079 | 3.202 |
| 毎回reset後 | 凍結lean | 60 | 2.712 | 2.933 | 3.017 |
| 状態を進める連続呼出し | 元モデル | 120 | 3.283 | 3.580 | 4.467 |
| 状態を進める連続呼出し | lean | 120 | 2.836 | 3.081 | 3.553 |
| 状態を進める連続呼出し | 凍結lean | 120 | 2.727 | 2.934 | 3.028 |

凍結によるleanからの中央値短縮は約0.129／0.109msだった。連続呼出しは実時間の50Hz運用ではない。凍結元モデルも含む全4種の計時値はJSONに収録した。

## 入力検査・変換を含むobserver再生

変更していないr5 observerへ元モデルと凍結leanを接続し、同じ保存snapshotで40組を比較した。先行順を交互に入れ替え、各モデル10回warmupと1回の保存入力による事前照合を終えてから、毎回reset後の`consume`全体を計時した。元の値・時刻は変更せず、CPU governor・affinity・優先度も変更していない。

| 対象 | モデル | 回数 | 中央値 ms | p95 ms | 最大 ms |
|---|---|---:|---:|---:|---:|
| observer全体 wall | 元モデル | 40 | 4.525 | 4.727 | 4.837 |
| observer全体 wall | 凍結lean | 40 | 4.091 | 4.283 | **6.610** |
| observer全体 呼出しスレッドCPU | 元モデル | 40 | 4.491 | 4.701 | 4.790 |
| observer全体 呼出しスレッドCPU | 凍結lean | 40 | 4.064 | 4.278 | 6.548 |
| うちモデル呼出し wall | 元モデル | 40 | 3.410 | 3.604 | 3.708 |
| うちモデル呼出し wall | 凍結lean | 40 | 2.995 | 3.186 | 5.037 |

40組中38組で凍結leanが速く、2組で遅かった。組ごとの差の中央値は0.439ms、表の中央値同士の差は0.435ms。最大6.610msの試行ではテンソル生成が2.265msとなった。別の遅い試行ではモデル呼出しが5.037msであり、区間の最大値を足さない。この記録だけで遅延の原因を凍結処理へ特定することもできない。

40組すべてで全observer結果、入力・出典、観測・目標、observer確定状態、reset後および呼出し後の11項目の可変状態が完全一致した。11ケースはモデル呼出し前、重力の特異姿勢1ケースはモデル内で拒否され、全12ケースの拒否理由・例外後状態・tick未確定も一致した。凍結controllerは`ScriptObject`で通常の`named_buffers`に列挙されないため、この再生では11項目を明示的に読む。全重み・全不変値を再生の各回で比較したという意味ではなく、重み等の別検証へ結果ハッシュで接続している。

保存された80回の計時、区間合計、組の順序、結果・reset状態・呼出し後状態のハッシュ、12拒否ケースを監査した。監査側でモデルを再実行した結果ではない。ローカルの4試験はpin・変換・拒否・比較除外範囲を確認する補助試験である。

前回の非凍結lean比較とobserverソースは同じだが、別の実行であり、計時前後に読む状態の範囲も異なる。**前回の元モデル中央値6.231msから今回4.525msへの変化を凍結の効果とは扱わない。** 今回のobserver差は「元モデル対凍結lean」で、凍結だけの効果は分離していない。保存入力の結果を実機全工程24.568msから差し引くこともできない。

同値性は成立したが、最大値の改善は成立していない。r7は非凍結leanで進め、凍結版の採用は保留する。今回の測定でハードウェア取得やモーターへの送信は行っていない。

元の凍結検証結果SHA-256：`9e72c3857ea3ce263c8c06ed0f2f5c2e1bdd4a212a3d35dcabf22d9fe01d1f89`。observer再生結果SHA-256：`f7ea31234bb0c1815131db15d40efed983c0668e64797e80aa63586e7242655a`。モデル・ソース・ハーネスのハッシュはJSONに収録した。

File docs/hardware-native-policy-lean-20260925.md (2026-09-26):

# 未使用の診断テンソルを省く推論候補 — 2026-09-25

**CPU単独の推論候補は、240ステップで既存モデルと完全一致し、中央値を約0.3ms短縮しました。ただし連続試験の最大値は悪化したため、実機統合前の候補として保持します。** 公開runtimeのソースや実機で使用するモデルは変更していません。値取得・推論・送信の20ms達成を示す結果ではありません。

[公開集計・ソースと成果物のハッシュ](../evidence/hardware-native-policy-lean-20260925.json) · [現行モデルの統合測定](hardware-post-firmware-remediation-20260925.md#実推論とstop代理送信を含む統合比較) · [20ms改善計画](hardware-remediation-plan-20260925.md)

## 変更した範囲

凍結候補`native-policy-lean-r1`は、配備用`forward`から使わない診断用テンソル・辞書値の作成を省きます。既存coreの12メソッドはAST比較で同一のまま保持し、4つの必要な中間値を返す`_step_inputs`と、最終目標だけを返す`step_target`を追加しました。配備用ラッパーの変更はcoreのimport先と呼出し先だけです。

actorの重み、投影演算のネイティブライブラリー、状態更新、範囲・有限値・投影結果の整合性検査は変えていません。途中の公開dtypeへの丸めと、その後の再変換も維持しています。既存の`step`や診断APIは残り、新しい呼出し経路が診断値の作成を省略します。別のアルゴリズム、重みの再学習、検査を外した高速化ではありません。

独立監査では6ソース／資料とmanifest、結果8ファイルのSHA-256・サイズを照合しました。ASTで既存メソッド、状態更新・検査の保持部分、必要な4値と変換、投影後検査、最終目標式の一致を確認しています。元manifestの`PREPARED_FILE_ONLY_NOT_EXECUTED`は準備時点の記録で、実行後の結果は別の`report.json`に保持しています。

## 一致を確認した内容

比較対象は固定済み既存JIT、元ソースから再生成したJIT、候補JIT、保存して再読込みした候補JITの4つです。

- 変化する合成入力240ステップを使用し、開始前・125番目前・全240ステップ後に状態をreset。
- 毎ステップ、最終目標、74次元観測、actor出力、全named buffer／parameterを照合。最大絶対差は全項目0、`torch.equal`による完全一致。
- 入力テンソルの破壊的変更がないこと、reset後の状態が一致することを確認。
- NaN／Inf／形状違い、重力正規化・特異姿勢、コマンド混在・上限、hの上下限など26ケースを全モデルが同じ理由で拒否。例外後の状態も照合。
- 候補を保存・再読込みしたモデルも同じ比較に参加。

これは指定した入力系列・異常ケースでの同値検証です。全入力空間の証明や実機出力の承認ではありません。監査側は固定ソースとハーネス、保存されたPASS結果を検査し、Jetsonでのモデル実行を再実行してはいません。

## CPU単独の時間測定

Jetsonの`torch 2.14.0+cpu`、intraop／interopとも1スレッド、`inference_mode`で測定しました。時間測定の入力は過去の統合試験02に保存された値です。240ステップの一致確認用合成系列とは分けており、保存入力を新しい実機テレメトリーとは扱いません。

| 条件 | モデル | 回数 | 中央値 ms | p95 ms | 最大 ms |
|---|---|---:|---:|---:|---:|
| warm済み・毎回reset後 | 既存 | 60 | 3.154908 | 3.403378 | 3.554454 |
| warm済み・毎回reset後 | 候補 | 60 | 2.8373165 | 3.139819 | 3.312144 |
| warm済み・状態を進める連続呼出し | 既存 | 120 | 3.1466995 | 3.403858 | 3.474835 |
| warm済み・状態を進める連続呼出し | 候補 | 120 | 2.859301 | 3.117452 | **3.956511** |

既存・候補を交互に実行し、各回の先行順を入れ替えています。20回のwarmup後に測り、毎回reset条件のreset自体は計時外です。連続条件は最初に1回resetし、同じ保存入力で状態を進めています。連続120回は50Hzの実時間制御ではありません。

中央値の短縮は約0.318ms／0.287msです。一方、連続条件の最大値は約0.482ms増えています。p95は保存ハーネスのnearest-rank方式であり、各回の生計時配列は保存されていないため、監査で分位点を再算出した結果ではありません。

計時対象はCPUの`forward`呼出しだけです。コンパイル・cold初回・reset・入力テンソル生成・同値確認・observerの検査と変換・センサー取得・送信・ファイル出力は含みません。**既存の統合試験で観測したモデル呼出し6.86〜10.72msとは実行条件が異なるため、「約7msから2.8msへ短縮」とは比較しません。** この候補の全工程短縮量は未測定です。

## 生成グラフと成果物

保存したinlined graphのノード数は既存／再生成既存が1,134、候補／再読込み候補が937でした。候補では対象の診断項目名が消え、ネイティブ投影演算の呼出しは残っています。実行後の最適化済みgraphも保存しました。ただしノード数やソース行数の減少を、そのまま高速化率とは解釈しません。

候補ファイルは`lean_policy_fileonly.pt`（194,326バイト）、SHA-256は以下です。

```text
022fb1bb07661804cc6a5060c39d0c76ddd767efb70a3800155af53f1a31f639
```

固定した元モデル・ライブラリー、候補ソース、ハーネス、manifest、入力元report、各graphと候補成果物のハッシュは公開JSONに収録しています。モデル本体・ソース・graphテキスト・入力の実値は本資料に含めていません。ハッシュの一致確認範囲と、実行結果の検証範囲を区別しています。

次は候補を新しい実機入力の準備・実推論・STOP代理送信まで接続し、同じ条件で基準と比較します。全工程の最大値、入力年齢、拒否条件、終了処理を確認してから採否を決めます。このCPU比較ではハードウェアを開かず、目標送信も行っていません。

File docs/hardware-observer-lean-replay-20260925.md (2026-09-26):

# 推論候補の入力検査を含むCPU再生比較 — 2026-09-25

**保存済み入力を使ったCPU比較で、入力検査・推論・出力変換の中央値は既存6.231ms、候補5.957msとなり、約0.274ms短縮しました。** 40組すべてで出力・観測・状態は完全一致しました。新しい実機入力の取得や送信は行っておらず、全工程20msの達成を示す結果ではありません。

[公開集計・各回の計時値・ハッシュ](../evidence/hardware-observer-lean-replay-20260925.json) · [候補モデルの先行同値検証](hardware-native-policy-lean-20260925.md)

未使用の診断値作成を省く既存のlean候補を、変更していない`integrated-stop-proxy-r5`のobserverに接続しました。重み、状態更新、範囲・有限値・投影整合性の検査は変えていません。公開runtimeや実機用モデルの置換は行っていません。

入力は完了済み`postfw-cadence-20260925-06-phase`の保存snapshotです。値と元の時刻を保持し、毎回resetして1回だけ消費しました。同じ保存値の再利用を新しい取得とは扱いません。hは0の仮説、コマンドは0のままで、校正と取付けの検証状態も変えていません。

| 計時対象 | モデル | 回数 | 中央値 ms | p95 ms | 最大 ms |
|---|---|---:|---:|---:|---:|
| observer全体：wall | 既存 | 40 | 6.231169 | 6.796903 | 7.000207 |
| observer全体：wall | 候補 | 40 | 5.957447 | 6.420376 | 6.777030 |
| observer全体：呼出しスレッドCPU | 既存 | 40 | 5.974064 | 6.137312 | 6.200352 |
| observer全体：呼出しスレッドCPU | 候補 | 40 | 5.711728 | 5.853216 | 5.937312 |
| うちモデル呼出し：wall | 既存 | 40 | 5.096341 | 5.570391 | 5.889859 |
| うちモデル呼出し：wall | 候補 | 40 | 4.800250 | 5.332654 | 5.663515 |

40組の先行順を交互に入れ替え、35組で候補が速く、5組では遅くなりました。組ごとの差の中央値は0.234msで、表の中央値同士の差0.274msとは別の統計です。p95はnearest-rank方式です。80回分の生計時値から全体・各区間の統計を再計算し、保存集計との一致を確認しました。

Jetsonの`torch 2.14.0+cpu`、intraop／interop各1スレッドで実行しました。両モデルとも10回の合成warmupと、1回の保存入力による同値確認を計時前に実施しています。計時対象はwarm済みの`observer.consume`全体で、snapshotのコピー、入力検査、変換、出典のJSONハッシュ、推論、出力検査、結果作成とtick確定を含みます。初回呼出し、reset、入力組立て、取得、送信、ファイル出力は含みません。

計時前と各試行で、保存済み結果との一致を確認しました。除外したのは計時情報と再生run番号だけです。40組ごとに全結果、入力、出典、12目標値、74観測値、12actor値、observer確定状態、全named buffer／parameter、reset状態を照合しました。テンソルは許容誤差を設けず`torch.equal`で比較し、snapshotが変更されていないことも確認しています。

さらに、非有限値・範囲外・欠落・重複・未来時刻・不正な年齢・tick違反など11ケースがモデル呼出し前に拒否され、状態を変えず、tickを確定しないことを確認しました。正規化された重力の特異姿勢1ケースはモデル自身の検査で拒否されました。両モデルの拒否理由と例外後状態は全12ケースで一致しました。これらは別途実施済みの240ステップ連続同値検証・26モデル入力拒否ケースを置き換えるものではありません。

これは1プロセス内の40組の比較です。計時前後の状態コピー・ハッシュがキャッシュやCPU周波数に影響し得るほか、実機の取得workerが動く条件とは異なります。CPU governor・affinity・優先度は変更していません。今回の最大値改善を最悪時遅延の保証とは扱わず、実機全工程から0.274msを差し引いて改善後の時間とすることもできません。候補の採否には、同じ条件での実機統合比較が残ります。

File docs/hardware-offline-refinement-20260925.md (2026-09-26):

# 入力コピーと推論準備の切り分け — 2026-09-25

**入力組立てのコピー削減は中央値約0.056ms、100ms待機後の再warmupはobserver中央値約0.282msを短縮した。保存入力での結果であり、実機全工程20msの達成ではない。** 最新の実機全工程は中央値22.283ms・最大23.193msのまま。

[公開集計](../evidence/hardware-offline-refinement-20260925.json) · [最新の実機測定](hardware-integrated-lean-20260925.md) · [待機スレッド比較](hardware-wait-contention-20260925.md)

## 入力組立て

| 保存入力の組立て | 回数 | 中央値 ms | 最大 ms |
|---|---:|---:|---:|
|現行の有界コピー |90|1.320122|2.514351|
|所有権が確定したCAN記録を借用して検査 |90|1.264136|1.496078|

3つの保存入力それぞれ30組、毎組の先行順を交替した。対象は組立て関数だけで、実デバイス取得や推論は含まない。候補はIMUと公開APIのコピーを保持し、私有の呼出し経路だけがCAN記録の新たなコンテナー生成を省く。型・深さ・要素数・byte上限、循環、有限値、内容と時刻の検査は維持。3つの出典ハッシュと完成snapshotハッシュ、出力全体、元入力が変わらないことを全90組で確認した。

ローカル119件中118件成功・1件skip、Jetson119件中117件成功・2件skip。skipは既存の非同梱記録に依存する試験。中央値の短縮は小さいため、この変更だけで残り約4msを解消できるとは扱わない。候補は私有検証パッケージ内に保持している。

## 準備後の待機とwarmup

| 保存入力の条件 | 回数 | observer中央値／最大 ms | モデル呼出し中央値／最大 ms |
|---|---:|---:|---:|
|reset・入力準備後すぐ実行 |24|4.013／4.297|3.091／3.307|
|その後100ms待機 |24|4.138／4.557|3.192／3.504|
|100ms待機後に10回warmupし、再reset |24|3.856／4.033|2.867／3.035|

2つの新しいプロセスで各12組を交互・逆順に実行した。全72回で保存出力、全parameter/buffer、observer内部状態、snapshotが完全一致。時刻の書換えはない。CPUは実機測定と同じperformance・既存上限1,497,600kHzで比較し、親・watchdog・外部読取りでschedutilへの復元を確認した。

100msの待機だけによる差は約0.126msで、実機統合時に見た数msの遅延を十分には再現していない。再warmupは追加計算であり、これを毎周期の計時外へ追い出せば高速化できるという意味ではない。

次の実機候補では、初期化時に行う既存10回warmupそのものを、機器準備・全12台識別確認の後、全センサー取得開始より前へ移す。回数を追加せず、初期化後に新しい入力を取得する。この順序変更の効果を全工程で確認するまでは、20ms短縮量に算入しない。

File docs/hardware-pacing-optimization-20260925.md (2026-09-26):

# 送信間隔・返信待ち件数の最適化 — 2026-09-25

更新：その後の0.6ms間隔・軽量モデル・入力所有権引渡しによる統合結果は、**中央値22.283ms／最大23.193ms**。[最新結果](hardware-integrated-lean-20260925.md)。以下は0.8ms条件までの記録を保持する。

**QDD・IMU取得→実推論→最後のSTOP代理送信まで、中央値24.568ms、最大25.037msとなった。** 3回とも完了し、欠測なし。前回の完了結果31.759msから約7.2ms短縮したが、20msには未達。最後の返信までを含めると中央値27.434ms、最大27.950msである。

[準備状態の記録](../evidence/hardware-pacing-optimization-20260925.json) · [全工程の既存結果](hardware-performance-refinement-20260925.md) · [CH340設定の確認](usb-latency-settings-20260925.md) · [残課題と対策](hardware-remediation-plan-20260925.md)

## 最初の比較条件

CPUを既存の周波数上下限内で一時的に`performance`にし、前後各バスの同時未返信件数を2件へ制限する。次の3条件を順番に実施した。返信・後処理が不完全なら後続条件へ進まない。

| 順番 | 同時未返信件数／バス | write復帰→次のwrite開始の最小間隔 | 取得回数 |
|---|---:|---:|---:|
| 1 | 2 | 1.0ms | 3回 |
| 2 | 2 | 0.8ms | 3回 |
| 3 | 2 | 0.5ms | 3回 |

各起動で全12台の識別を照合してから、前後6台ずつ並列に取得する。1回の取得には各IDへ全0のType4停止命令を1フレームずつ送り、位置・速度等を含むType2返信を受ける。結合書込み・モーター有効化・目標位置送信・自動再試行はない。最大48回の個別17バイト書込み、取得の全体期限10秒である。IMU・学習モデルはこの通信単独比較には含めない。

CPU比較の前回失敗ではID4・10の返信が欠けた。欠測の直前に未返信は2件であり、「4件同時だったから」とは断定できない。今回は2件制限と送信間隔を明示し、同一の処理で比較する。設定値だけでなく実際の送信間隔・未返信件数・欠測・最終返信時刻を確認する。

## 実機結果

全条件でCPUは既存上限1,497,600kHz内の`performance`。工程の計時外でUID照合し、同じ停止状態・同じプログラムで各3回の取得を比較した。下表は通信単独の取得開始から全12返信までであり、IMU・推論・後段送信を含まない。

| 同時未返信上限 | 最小送信間隔 | 取得中央値 | 最大 | 結果 |
|---:|---:|---:|---:|---|
| 2 | 1.0ms | 11.477ms | 11.602ms | 3回完了 |
| 2 | 0.8ms | 10.590ms | 10.884ms | 3回完了 |
| 2 | 0.5ms | — | — | 初回のID2・8返信欠落で中断 |
| 3 | 0.8ms | **8.720ms** | **8.729ms** | 3回完了 |
| 4 | 0.8ms | 8.786ms | 8.980ms | 3回完了。実際の最大未返信は3件 |
| 2（再比較） | 0.8ms | 10.554ms | 10.811ms | 3回完了 |

欠測した条件では各バス12送信・11返信（UIDを含む）。CPU設定を復元し、通常の全12台確認に成功してから後半の比較へ進んだ。完了した各条件は48送信・48返信で、生バイトからフレームと時間を再計算して照合した。0.5ms失敗は改善値から除外している。

3件／0.8ms条件の実際の送信間隔中央値は前0.943ms・後0.942ms、全12台の最初〜最後のホストwriteは中央値5.941msだった。0.5ms条件の最短実間隔は前0.648ms・後0.631msで、指定下限を破った結果ではない。欠落箇所がUSB基板・CAN・受信側のどこかは、これだけでは確定できない。

この有限比較では3件上限を次の統合測定に選ぶ。4件上限の方が速いとはいえず、3回ずつの結果を長時間の安定性やp99保証には使わない。両比較後のCPU governorは、親処理・独立watchdog・外部読取りで`schedutil`への復元を確認した。

## 完了判定と設定の復元

- 全12台のUID一致、各条件48送信・48返信、STOP返信のmode0／fault0。
- 生受信バイト・フレーム・送信時刻・返信対応を照合。欠測、重複、残留バイト、期限超過、設定より短い送信間隔は不合格。
- 全ワーカー、ポート、起動確認用FD、排他ロックの終了を確認。
- CPU設定は親処理と独立watchdogで復元し、外部の読取りでも確認する。周波数上下限・電力モードは変更しない。

3回とも同じ入力取得工程として測る。後段の代理送信工程にだけ必要だった追加の起動確認を途中の回へ混ぜない。取消・期限・返信対応の検査は各操作に残す。起動IDの確認は工程境界で行い、同一キーの極端に遅れた前周期返信をプロトコルだけで完全識別できない制限も維持する。

通信ツールはオフライン89件を実行（既存の非同梱記録を使う1件はskip）。実際の`select`／`os.read`の試験はローカルのsocket pairを使用し、ロボット通信の成功とは数えていない。CPU復元・子プロセス所有権の32件、生ログ照合の5件（改変した29条件の拒否を含む）も成功した。

## 実入力・実推論・STOP代理送信の統合結果

接続復帰後の起動IDと前後USB対応を確認し、実機側のファイルをハッシュ照合した。通信ツールは実機上のオフライン25件も成功した（最初は比較用の旧ソースファイルが非同梱だったため1件エラーとなり、同一ハッシュのテスト用資料を配置して解消）。

0.8ms・3件上限を入力取得と代理送信の両方へ反映した統合版を配置済み。モデル・校正値・範囲検査は従来と同じで、入力が範囲外なら推論・後段送信へ進まない。ローカル67件（1skip）、Jetsonのオフライン67件（2skip）、監視・復元・ログ検証57件を確認した。

一度は姿勢合わせが難しく保留したが、その後ユーザーが姿勢を整え、開始を確認してから3回実行した。関節範囲・校正値・記録時刻は変更していない。

| 工程 | 中央値 ms | 最大 ms |
|---|---:|---:|
| QDD・IMU並列取得 | 9.073 | 10.119 |
| 入力組立て | 1.643 | 1.702 |
| 入力検査・実推論・結果変換 | 6.023 | 6.851 |
| 最初〜最後のSTOP代理write | 6.399 | 6.619 |
| **最古入力開始→最後のホストwrite復帰** | **24.568** | **25.037** |
| 最古入力開始→最後の返信 | 27.434 | 27.950 |

各回の全工程は24.568／23.667／25.037ms。CPUを既存の上下限内で一時的にperformanceへ設定し、入力と送信をともに3件／0.8msへ変更した。前回値との比較では複数の条件が変わっているため、約7.2msの差を通信設定だけの効果とは断定しない。工程別の中央値は足し合わせない。

各回36個の17バイトwriteと36返信を確認し、生バイト・フレーム・UID・時刻・mode0／fault0・送信間隔・未返信上限を照合した。3回すべてでIMU設定の復元、ポート・ワーカーの終了、排他解放が完了。CPUは親処理・独立watchdog・外部読取りでschedutilへの復元を確認した。保存した時刻から全工程を再計算するオフライン監査も成功した。

推論は元のモデルで、後段送信は全0の停止命令である。診断値生成を省く候補モデルはこの実入力試験には使っていない。ホストwrite復帰はCAN線上の送信完了ではなく、3回の単発成功も連続50Hzや学習済み目標を送る制御の証明ではない。

別途、入力の二重コピーと固定テンソル生成も監査した。既存記録ではsnapshotコピー約0.345ms、テンソル生成全体約0.380msであり、これだけで約12msの不足を埋められるとは判断しない。範囲・有限値・時刻・故障の検査を残して、同値性を確認した変更だけを比較する。

現在の不足は最後のホストwriteまでで中央値約4.6ms、最大約5.0ms。次は入力組立て・モデル呼出しのCPU処理と、約6.4msの送信区間を分けて短縮する。診断データ削減だけで不足を埋められると見込まず、Type2状態の連続受信による問い合わせ削減も優先候補とする。0.5msへ単純に詰める変更は、欠測が発生したため採用しない。

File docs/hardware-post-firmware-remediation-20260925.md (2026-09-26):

# FW更新後の通信再検証と残課題 — 2026-09-25

後続の[起動確認ガード分離・warmup比較](hardware-performance-refinement-20260925.md)では、別の各3回比較で全工程中央値40.384→35.706msを観測した。本資料はそれ以前の通信修正と入力組立て比較の記録として保持する。

**全12台のRS05は0.5.0.13です。6台の自動報告開始はまだ安定していませんが、失敗後の解除・STOP確認は修正後の実機試験で完了しました。値取得・実推論・STOP代理送信の各3回比較は、基準37.151ms／改善候補37.200ms（最古入力から最終ホスト書込みの中央値）で、全工程20msや全体の改善は未達です。** 最終確認では全12台の停止返信・受信静穏・ポート閉鎖を確認しています。

[公開集計・記録ハッシュ](../evidence/hardware-post-firmware-remediation-20260925.json) · [全12台のFW更新記録](rs05-firmware-update-success-20260925.md) · [現在の改善計画](hardware-remediation-plan-20260925.md)

## 今回の条件と結果

初回00〜05は、凍結した更新用r5に含まれる受信ツールで、更新前のActive Reporting r5に合わせて、対象ID・1秒の計測窓・Type24の周期報告・開始／解除時のType2分離・約20msの送信間隔を指定しました。周期設定は変更せず、`0x7026`の生値0をそのまま観察しています。生値0の一般的な意味は未確定です。UARTは921600bps、モーターのenable・駆動目標は送信していません。

| 記録 | 条件 | 観測と判定 |
|---|---|---|
| 00 | 全12台の事前確認 | 全台の版数`00 05 00 0D`、識別一致、STOP返信mode0／fault0、受信静穏 |
| 01 | ID3単独・1秒 | 計測窓内100件、間隔中央値10.011743ms、最大10.308521ms。OFF・静穏・別区間STOPまで成功 |
| 02 | ID1・2・3、ID3から解除・1秒 | 計測窓内99／100／100件、計299件。全ID中の最大間隔10.441804ms。全台のOFF・静穏・別区間STOPまで成功 |
| 03 | 前6台、ID3から解除する条件 | ID1・2・5・6だけ開始応答を観測。ID3・4はON後のType2もType24も0件。1秒の計測窓へ入る前に失敗 |
| 04 | 独立した前6台の解除・復旧 | 全6台のOFF後Type2、100ms静穏、識別再照合、STOP返信を確認。受信したType24は0件 |
| 05 | 全12台の再確認 | 全台0.5.0.13、識別一致、STOP返信mode0／fault0、前後各受信静穏。両ポート閉鎖・排他解放 |

01・02はそれぞれ1試行です。約100Hzはホスト受信の観測であり、モーター内部のサンプル時刻やCAN線上の完了時刻ではありません。計測窓の境界を跨ぐフレームは件数から除外しているため、02の299件だけで1件の物理欠落とは判定しません。

## 6台試験の開始失敗と、解除時のソフトウェア課題

03では全6台へONを各17バイト書き込みました。ID3・4への書込みも完了していますが、CAN線上へ出たことや、モーターが受理したことまでは証明できません。開始時に観測できたType2はID1・2・5・6の4件、全ログ中のType24はそれぞれ32／32／29／29件でした。ID3・4のType24は全ログを通して0件です。

以下は、最初のONのホストwrite開始を0msとした時刻です。OFF後Type2は各OFFのwrite開始から受信完了までで、STOPへの応答とは区別しています。

| ID | ON開始 ms | OFF開始 ms | OFF後Type2受信 ms |
|---|---:|---:|---:|
| 1 | 0.000000 | 315.995147 | 3.302002 |
| 2 | 21.198495 | 337.184969 | 3.333268 |
| 3 | 42.387613 | 294.864494 | 3.418071 |
| 4 | 63.509370 | 358.282213 | 3.291922 |
| 5 | 84.832989 | 379.357119 | 3.450840 |
| 6 | 105.937465 | 400.421177 | 3.414551 |

294.275098msの受信処理でID3の開始確認期限を超え、受信解析を失敗として停止しました。その時点ではID6のType24が15バイトまで届き、末尾の2バイトを待っていました。次のreadで**1.909730ms後に残りが到着**しています。しかし失敗後の解除処理は生バイトの保存だけを続け、停止したパーサーへ渡さなかったため、以前の15バイトが残りました。

全生ログ2,652バイトを独立して解析すると、156個の完全なフレームとなり、最後の残留は0バイトでした。保存された受信サンプル95件も順序・時刻を含めて再現しています。これは不正な末尾バイトが新たに届いた事例ではなく、解析停止後のパーサー状態を新しい問い合わせの判断に使った問題です。

解除命令は順にID3→1→2→4→5→6へ各17バイト送られ、全台のType2が生ログにあります。各台のOFF送信後のType24は0件でした。それでも古い残留を検出したガードにより、最終STOPは**送信前に拒否**されました。元の開始失敗と、この解除確認の問題は別の課題です。

修正版は、報告区間の全生バイトを独立したパーサーで最初から順に再解析し、対象ID・型・mode／fault・フレーム境界と100ms静穏を確認してから、別区間のSTOP照合へ進めます。残留を捨てて成功扱いにはせず、開始失敗の判定も保持します。保存03ログによる回帰試験に加え、下記08で実機の失敗経路を検証しました。

空のreadの時刻は全件記録されていません。静穏は保存された成功フラグと制御の経路、全生ログの末尾残留0の範囲で確認しています。03の`quiet_observed=false`は最終STOP拒否時にも設定されるため、それだけで報告が継続していたとは判断できません。03自体を成功へ変更せず、04の独立復旧と05の全台再確認を別の成功記録として保持します。

## 受信・解除修正後の実機確認

06〜09は新しい受信器を含む凍結版`postfw-receiver-r1`による試験です。元の欠測を成功へ変える変更は含みません。

| 記録 | 条件 | 観測と判定 |
|---|---|---|
| 06 | 全12台の事前確認 | 全台0.5.0.13、識別一致、STOP返信mode0／fault0、受信静穏 |
| 07 | ID3単独・1秒 | 計測100件、間隔中央値10.008668ms、最大10.260581ms。解除・静穏・最終STOPまで成功 |
| 08 | 前6台、ID3から解除 | ID1〜5の開始Type2を確認、ID6は開始Type2・Type24とも0件。計測開始前に失敗。全台OFF・独立した生ログ解析・静穏・最終STOP6台まで成功 |
| 09 | 最終の全12台確認 | 全台0.5.0.13、識別一致、STOP返信mode0／fault0、前後静穏。両ポート閉鎖・排他解放 |

08はON6回・OFF6回をすべて各17バイト書込み済みです。全送信42回の内訳は識別6・周期読取り6・電圧読取り6・STOP12・ON6・OFF6です。生受信3,485バイトは205フレームで、Type24はID順に35／35／28／33／33／0件でした。ID1・2・4では、それぞれのOFF送信後にType24が1件ずつ届いています。解除直後の残りの返信も検査対象に含めており、「OFF後に一切受信しなかった」とは扱いません。

解除の独立解析は報告区間2,975バイト・175フレームを再現し、破棄0・末尾残留0でした。続いて全6台のSTOPを実際に送信し、全返信を確認しました。**開始は失敗、失敗後の解除確認は成功**という結果を保持しています。この6台の解除成功は修正版で1試行であり、6台運用の安定性を示す結果ではありません。

## 更新前と比較できること

| 対象 | FW 0.5.0.9のr5 | FW 0.5.0.13の今回 |
|---|---|---|
| ID3単独 | 1秒100件、解除まで成功 | 1秒100件、解除まで成功 |
| ID1・2・3 | 1秒各100件。ただしID1・3のOFF後も報告継続 | 1秒99／100／100件、全台の解除・STOPまで1回成功 |
| 前6台 | ID6の開始応答が欠け、計測前に失敗。解除後もID3の報告継続 | 初回03はID3・4欠測。修正後08もID6欠測で計測前に失敗。08は全OFF・静穏・最終STOPまで成功 |

上表の旧FW r5と初回01〜03では、プロトコル・受信器・パーサー・受信待機のソースは同一ハッシュです。試験本体の状態遷移も同じですが、起動確認は毎回のファイル開閉から`BootIdentityGuard`へ変更されています。ホスト処理時間と送信位相は完全同一ではありません。各条件1回のため、3台解除の改善をFWだけの効果と断定せず、再現性の確認を続けます。後6台・前後12台の自動報告にはまだ広げていません。

## CPUコピー単独比較

Jetsonの保存データ3件を各1,000回使い、従来の`deepcopy`と有界のJSON互換コピーを比較しました。出力内容・元の時刻は全件一致しました。以下はコピー処理だけのホスト経過時間です。

| 保存データ | 旧中央値 ms | 新中央値 ms | 旧最大 ms | 新最大 ms |
|---|---:|---:|---:|---:|
| 01 | 0.251848 | 0.134052 | 0.276457 | 1.739643 |
| 02 | 0.249960 | 0.133572 | 0.277161 | 0.301227 |
| 03 | 0.253032 | 0.133924 | 0.272617 | 0.297770 |

中央値は約0.116〜0.119ms短くなりましたが、最大値は全3件で増え、01では1.739643msでした。新しいセンサー値の取得、モデル推論、送信は測っておらず、同じ保存入力の1,000回再生を新規1,000サンプルとは数えません。以前の入力組立て比較とは対象が違うため、[更新前の記録](hardware-active-reporting-20260925.md#入力組立ての改善)からの差や短縮幅の単純加算には使いません。

## 実推論とSTOP代理送信を含む統合比較

最初の01は入力取得14.345738ms、入力組立て3.724119msの後、`Calibrated position outside registered joint range; no clipping`で中断しました。全12台の識別・入力用STOPの24要求とIMU取得は成立しましたが、推論と後段送信は未実施です。範囲検査を緩めず、ユーザーによる姿勢合わせの後、02〜07を基準→改善候補の順に交互に実施しました。

モデル・ライブラリー・ソース・FWは同一で、切替えた実験条件は入力組立て方式だけです。各回で新しい実機入力を取り、学習済みモデルを実行しました。推論結果はモーターへ送りません。後段送信は全0のType4 STOPで代理測定しました。前後のCANとIMUは既に並列です。

| 工程・範囲 | 基準 中央値 ms | 基準 最大 ms | 改善候補 中央値 ms | 改善候補 最大 ms |
|---|---:|---:|---:|---:|
| 入力取得 | 13.140767 | 13.148734 | 10.872182 | 12.968249 |
| 入力組立て | 3.982430 | 4.095329 | 3.439980 | 3.552080 |
| 入力検査・実推論・結果変換 | 9.632112 | 9.907064 | 10.635535 | 13.746289 |
| うちモデル呼出しのホスト経過時間 | 7.144577 | 7.223300 | 7.839831 | 10.721234 |
| 最初の代理write開始→最終write復帰 | 9.301957 | 10.011932 | 8.788373 | 9.225155 |
| **最古入力取得開始→最終write復帰** | **37.150610** | **37.774409** | **37.199636** | **37.763557** |
| 最古入力取得開始→最後の返信 | 39.340311 | 40.051249 | 40.063438 | 40.567005 |

各方式3回の単発試験です。入力組立ての中央値は短くなりましたが、全工程の中央値は短くなっていません。入力取得や推論に変動があり、今回の3回ずつだけでは改善候補が全体を高速化したとは言えません。統計的有意差の検定は実施していません。工程ごとの中央値は同一回の値とは限らず、足し算して全工程値とはできません。6回のモデル呼出しは6.861817〜10.721234msでした。

成功した6試行は各バス18送信・18返信（識別6、入力STOP6、代理STOP6）で、全書込み17バイト、受信末尾残留0、全Type2がmode0／fault0でした。推論は各試行1回、全6回です。01の失敗を含む全7試行でworker終了、ポート閉鎖、排他解放、IMU設定復元を確認しました。保存生バイトから復元した全フレームも保存された返信と一致しています。

`torch 2.14.0+cpu`を使用し、モデル・ネイティブライブラリー・実行manifest・25ソースのハッシュを公開JSONに保持しています。warmupと識別要求は計時範囲外です。ホストwrite復帰はCAN線上の送信完了ではなく、センサー内部サンプル時刻も未検証です。通常駆動、学習済み目標の通信、50Hzの連続制御、全工程20msの実証にはなりません。

## 20msへ向けて優先する対策

| 優先 | 対策 | 必要な確認 |
|---|---|---|
| 1 | 独立した受信処理で返信・自動報告を保持し、毎周期の問合せ待ちを減らす | 6台の開始欠測を解消する。元の時刻・全関節の鮮度上限・関節間時刻差を保持し、欠測／古い入力は停止へ移る |
| 2 | 入力準備とモデル本体を測り、周期内の不要なコピー・診断処理・テンソル生成を減らす | 同じ入力系列で出力・内部状態・拒否条件の一致を確認。モデル呼出し6.86〜10.72msも対象にする |
| 3 | 前後6台ずつの送信と受信待ちを分離し、ホスト側の送信間待ちを減らす | 17バイトの個別writeを維持する。3／6フレームの一括UART書込みは再採用せず、返信の対応・期限・異常停止を維持する |
| 4 | CAN線上を受動観測し、USB基板の送出・QDD応答・USB受信を切り分ける | ホストの書込み完了だけで送出済みとみなさない。通信制約が残る場合は別transportを同条件で比較する |

設計目標は**取得5ms＋入力組立て・推論8ms＋送信4ms＋余裕3ms＝20ms**です。これは未測定の配分で、達成予測ではありません。20msごとに処理を開始できることと、最古の入力から出力まで20ms以内であることを別に測ります。10ms間隔の報告をキャッシュしても入力の古さは0になりません。受信時刻だけでなく、分かる範囲の取得開始時刻からの年齢と、内部サンプル時刻が不明な分も区別します。

## 記録の範囲

初回00〜05の29ファイルと追加43ファイル、合計72ファイルのSHA-256を照合しました。初回の47ソース、新受信器の48ソース、統合試験の25ソースも各凍結記録と一致しています。ローカル全体971テスト、Jetsonで保存03ログ回帰を含む134テストの成功は実行担当の検証結果です。本監査では同テスト群の再実行はしていません。

公開JSONはID・版数・集計値・ファイル名とハッシュに限定し、写真、生フレーム、個体UID、接続先、私的保存先は含めません。最終09で全12台の停止返信と前後の報告静穏を確認し、ポート・排他を解放しました。報告スイッチの直接読戻しや物理停止時刻の検証とは区別しています。後6台・前後12台の自動報告や、その後の新しい高速化候補は本記録の対象外です。

関連候補：[未使用の診断テンソルを省くCPU単独比較](hardware-native-policy-lean-20260925.md)。本記録の実機統合測定には未適用です。

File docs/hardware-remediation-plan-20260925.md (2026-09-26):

# 現在の課題と解消手順 — 2026-09-25

最新の無出力実測は、返信検査もC++化して**中央値20.063ms・最大20.136ms**。3回中1回は19.785ms、全回20ms未満は未達。入力テンソル生成と証跡整形が次の分析対象。[詳細と限界](hardware-native-host-processing-20260925.md)。

最新の実機計測：[初期化順序の改修・3回の生ログ検証](hardware-warmup-order-20260925.md)。

追加切り分け：[待機スレッド比較](hardware-wait-contention-20260925.md)、[コピー削減・推論準備比較](hardware-offline-refinement-20260925.md)。いずれも保存入力によるCPU比較で、実機20msの達成値を更新するものではない。

**最新の実入力比較は中央値21.234ms、最大21.865ms。3回とも欠測なく完了したが、20msには未達。** QDD・IMU取得→同値検証済み軽量モデルの実推論→最後のSTOP代理送信を測定した。返信完了まで含めると中央値24.070ms、最大24.582ms。既存10回warmupを12台識別・IMU初期化後へ移し、新しい入力取得の前で完了させた。入力の所有権を一度だけ引き渡し、通信間隔を0.6ms、同時未返信上限を3件とした。CPUは既存の周波数上下限内で一時的にperformanceとし、試験後の復元を確認済み。

[前回の統合測定・生ログ検証](hardware-integrated-lean-20260925.md) · [通信間隔0.8／0.7／0.6msの比較](hardware-fine-pacing-20260925.md) · [保存入力での推論処理最適化](hardware-observer-lean-replay-20260925.md) · [追加freeze候補の最大時間悪化](hardware-native-policy-freeze-20260925.md)

[最新の確認頻度・ガード分離・warmup比較](hardware-performance-refinement-20260925.md) · [更新後の通信・入力組立て比較](hardware-post-firmware-remediation-20260925.md) · [全12台のFW更新成功記録](rs05-firmware-update-success-20260925.md) · [実機投入までの残条件](hardware-summary-20260924.md)

## 入力組立て方式の過去比較（ガード分離より前）

| 工程 | 基準3回の中央値／最大 ms | 改善候補3回の中央値／最大 ms |
|---|---:|---:|
| 入力取得 | 13.141／13.149 | 10.872／12.968 |
| 入力組立て | 3.982／4.095 | 3.440／3.552 |
| 入力検査・実推論・結果変換 | 9.632／9.907 | 10.636／13.746 |
| 代理送信の最初のwrite→最後のwrite復帰 | 9.302／10.012 | 8.788／9.225 |
| **最古入力取得開始→最後のwrite復帰** | **37.151／37.774** | **37.200／37.764** |
| 最古入力取得開始→最後の返信 | 39.340／40.051 | 40.063／40.567 |

同一FW・モデル・ソースで入力組立て方式だけを切り替えた、各3回の単発測定である。入力組立ては短くなったが、全体の改善は確認できない。工程別の中央値は足し合わせない。推論は実モデルを使い、後段は全0のType4 STOP代理送信。学習済み目標は送っておらず、通常駆動や50Hz連続制御の実証ではない。warmupと識別要求は計時範囲外、ホストwrite復帰とCAN線上の完了も区別する。

前後CAN・IMUの取得と、前後CANの送信は既に並列である。単にスレッドを増やすだけでは解決しない。モデル呼出し単独でも今回6.862〜10.721msかかっている。

## 20msの設計予算と優先対策

以前の境界確認条件では、取得中央値9.879ms、入力組立て3.587ms、入力検査・推論・変換9.369ms、代理送信区間7.768ms、全工程31.759ms（最大33.226ms）だった。取消・期限・受信の対応検査は各操作で維持し、起動IDだけを明示した境界でfreshに読む条件である。warmup10→260回のCPU単独比較は初回中央値3.595→3.267msで、統合時のモデル呼出し約6.9msとの差の原因はまだ確定していない。

CPU governorを既存の周波数上下限内で`performance`へ切り替えた別試行は、入力STOPのID4・10への返信が欠けて中断した。3回予定のうち1回だけで、推論と後段送信には進んでいない。親処理・独立watchdog・外部読取りで元の`schedutil`設定への復元を確認した。全12台の通常読取りも再確認済みである。この中断した試行から全工程の改善値は得られていない。

[比較ツールの準備・検証記録](hardware-pacing-optimization-20260925.md)。再接続後、0.8ms・未返信3件で通信単独の全12台取得は中央値8.720ms／最大8.729ms（3回、欠測なし）。0.5msは返信欠落で中断した。その後の実入力統合比較も3回完了し、全工程中央値24.568ms／最大25.037msとなった。CPU条件と通信条件が変わっているため、短縮を一要因だけへ帰属しない。

同時未返信件数2／3／4と送信後の最小間隔0.5／0.8／1.0msの有限比較は完了し、次の統合条件に3件／0.8msを選んだ。欠けた4台目の送信直前には既に最初の返信を受けており、未返信件数は2件だったため、window=4だけを原因とは断定しない。設定間隔を守っていても基板側が処理できるとは限らず、欠測を無視して速度だけを合格にしない。

姿勢保持が難しい間に実施した保存入力のobserver比較では、診断データを減らす候補が中央値6.231ms→5.957ms、最大7.000ms→6.777ms（各40回）。出力・内部状態・12種の異常入力の拒否は一致した。その後、この軽量候補・所有権の一回引渡し・0.6ms間隔を組み合わせた実入力試験を3回完了した。全工程は中央値22.283ms、最大23.193msで、中央値約2.3ms、最大約3.2msの不足が残る。複数の条件を変更したため、短縮をモデル単独へ帰属しない。モデル呼出し自体は3.730／5.993／5.303msと変動した。保存した今回の実入力で、姿勢・初回呼出し・CPU競合の影響を切り分ける。

今回の3入力を保存して計66回の単独再生も行い、元モデル／leanの全出力・内部状態は一致した。leanの初回モデル呼出しは3.066〜3.440msで、統合時の最大5.993msは再現しなかった。その後、統合と同じperformance条件で180回の待機スレッド比較を実施したが、2msポーリング→期限付き通知待機の中央値差は約0.002msで、有効な短縮は確認できなかった。

入力組立ての重複コピー削減は保存入力90組で中央値1.320→1.264ms（約0.056ms短縮）。別の72回比較では、100ms待機後のobserver中央値4.138msが再warmup後3.856msになった。いずれも全出力・内部状態の一致を確認したが、実機の数msの遅延はまだ十分に再現していない。その後、既存10回warmupを機器準備の後・新しい入力取得の前へ移した統合比較を3回完了。入力検査・実推論・結果変換は中央値4.492ms、モデル呼出し単独は3.255～3.515msとなった。全工程は中央値21.234ms・最大21.865msで、次は取得と送信に残る待ちを分析する。保存入力の時間を全工程から単純に引かない。

**取得5ms＋入力組立て・推論8ms＋送信4ms＋余裕3ms＝20ms**を設計予算とする。各値は未達・未測定の目標配分で、現在のCH340構成で達成できるという予測ではない。

| 優先 | 課題 | 対策 | 完了条件 |
|---|---|---|---|
| 1 | 統合時の入力取得が中央値8.573ms。周期ごとの問合せ待ちが残る | 独立した受信処理でType2返信／Type24報告を受け取り、時刻付き状態を保持する。実制御ではType1制御返信を次の入力へ利用する構成も検討する | 自動報告の6台開始・解除が繰返し成立。全軸の鮮度上限、関節間時刻差、遅着・欠測時の停止を検証する。制御中の入力取得にType4 STOPは使わない |
| 2 | 入力組立て中央値1.808ms、入力検査・推論・結果変換4.492ms | snapshot再コピーを省き、所有権の一回引渡しは約0.014ms。次は入力組立て中の重複検査・証跡整形を分析する。モデル本体の費用を独立測定し、同じ入力系列で最適化候補を比較する | 出力・内部状態・異常時の拒否が一致。新しい入力を毎回準備する費用を含めて統合測定する |
| 3 | 代理送信区間が中央値5.830ms | 前後6台の受信待ちと送信を分離し、送信可能時刻→実writeの待ちを測って削減する。6台分を事前準備しても物理writeは各17バイトに保つ | 返信の対応、期限、部分write、取消、異常終了の判定を維持。3／6フレームを連結したUART書込みは禁止を継続する |
| 4 | 6台開始時の欠測が再現。USB基板／QDD／ホストのどこか未確定 | CAN線上の受動観測でON送出と返信を確認する。制約が残れば、Linux対応と29ビット拡張IDを確認した別transportを比較する | 同じFW・配線・要求で送出、QDD応答、USB受信を照合し、変更要因を一つに限定する |
| 5 | 実機投入条件が未完了 | 校正、再投入後の角度継続性、Type2速度倍率、IMU軸・重力推定、負荷履歴入力h、目標範囲と全軸停止を確定する | 診断用仮値を制御用へ無断昇格せず、支持下保持→補助付き立位→短い低速歩行へ進む |

**20ms周期と、最古入力から出力まで20ms以内は別条件である。** 10ms間隔の報告をキャッシュしても入力年齢は0にならない。受信時刻と取得開始時刻を保持し、入力の古さ、軸間の時刻差、内部サンプル時刻が不明な範囲を記録する。古い入力の再利用や未返信のまま先へ進むことで達成扱いにはしない。

## 通信修正の到達点

起動確認を所有FD＋fresh `pread`へ共通化した過去の個別STOP比較では、38.281ms→30.223msを各1回観測した。[r7記録](hardware-stop-guard-20260925.md)。これは今回の全工程に同じ短縮幅を足せる根拠ではない。

FW更新後、単台の約100Hz報告と解除は初回・修正版で各1回、3台は初回1回成功した。前6台は初回にID3・4、修正版にID6の開始応答・報告が欠け、いずれも計測開始前に失敗した。初回は解析停止時の15バイト残留を古いまま判断したため、解除後の最終STOPも送信前に拒否された。

修正版は報告区間の全生バイトを別パーサーで一度ずつ再解析する。実機08で2,975バイト／175フレーム、破棄0・末尾残留0、100ms静穏、全6台の最終STOP返信まで確認できた。開始失敗はそのまま保持している。解除成功1回を6台運用の安定性とは扱わず、後6台・前後12台へはまだ拡大していない。全12台の最終確認はFW0.5.0.13、識別一致、STOP mode0／fault0、静穏、ポート閉鎖・排他解放で完了した。

送信・受信の期限、取消、送信直前の所有権とポート確認は維持する。重複検査を整理する際も、抜差しや再起動検知をキャッシュで省略しない。読取り直後に異常となったバイトも保存し、「受信なし」と「受信したが採用不可」を区別する。

## CPU側で先に進めること

コピー単独の保存データ比較は、内容と元の時刻が一致し、中央値約0.250ms→0.134msとなった。ただし最大は0.277ms以下→1.740msへ悪化した例もある。[CPU単独比較](hardware-post-firmware-remediation-20260925.md#cpuコピー単独比較)。今回の統合比較でも全工程は改善していないため、中央値だけで採用しない。

1. 同じモデル・同じ入力系列・同じ内部状態の初期化で、モデル本体と入力準備の費用を分離する。
2. 不変レコードと有界バッファで所有権を明確化し、不要なコピー・診断整形・テンソル生成を周期外へ移す。新しい入力、時刻、故障、範囲との対応は維持する。
3. 出力とモデル内部状態を全件照合する。単独試験の短縮値を統合時の短縮量として流用しない。
4. 通信・IMU担当とのCPU競合を測り、スレッド設定や担当分離を一要因ずつ比較する。

warmup、`inference_mode`、推論スレッド数1は既に適用済みで、新しい改善策には数えない。以前の1バス分のフレーム解析・値変換は合計約0.06msだったため、パーサーだけのC++化を最優先にはしない。

## 通信機器の切り分けと次の判定

CAN 1MbpsとUART 921600bpsは別設定である。現在のホスト測定はCAN線の速度・完了時刻を保証しないため、UARTや無関係な`can0`を推測変更しない。受動観測で送出と応答を分け、それでも欠測や通信待ちが支配的なら、現在のCH340経由とLinux対応SocketCAN機器を同条件比較する。29ビット拡張ID、1Mbps、前後2バス、受信時刻、エラーフレーム、bus-off通知を確認する。[Linux公式SocketCAN資料](https://docs.kernel.org/networking/can.html)

別機器の採用だけで20msは保証されない。同じモーター・FW・配線・要求で比較し、同型USB基板の増設より先に待ちと欠測の箇所を明らかにする。

次はオフライン同値検証→有限の停止中通信比較→入力・実推論・STOP代理の統合比較→10秒／60秒の有限連続測定の順に進める。中央値だけでなく最大・p95／p99・欠測・期限超過・入力年齢を記録する。STOP代理と駆動中Type1の往復は別に検証し、実出力は投入条件が揃ってから支持下で開始する。

## 根拠

- [今回の通信回帰・CPU比較・統合各3回](hardware-post-firmware-remediation-20260925.md)
- [全工程の過去測定](control-20ms-strategy-20260924.md)
- [自動報告・入力準備の過去比較](hardware-active-reporting-20260925.md)
- [まとめ送信の失敗と復旧](hardware-stop-batch-20260925.md)
- [全12台のFW更新と設定照合](rs05-firmware-update-success-20260925.md)

- [未使用の診断テンソルを省く候補：初期のCPU単独同値比較](hardware-native-policy-lean-20260925.md)

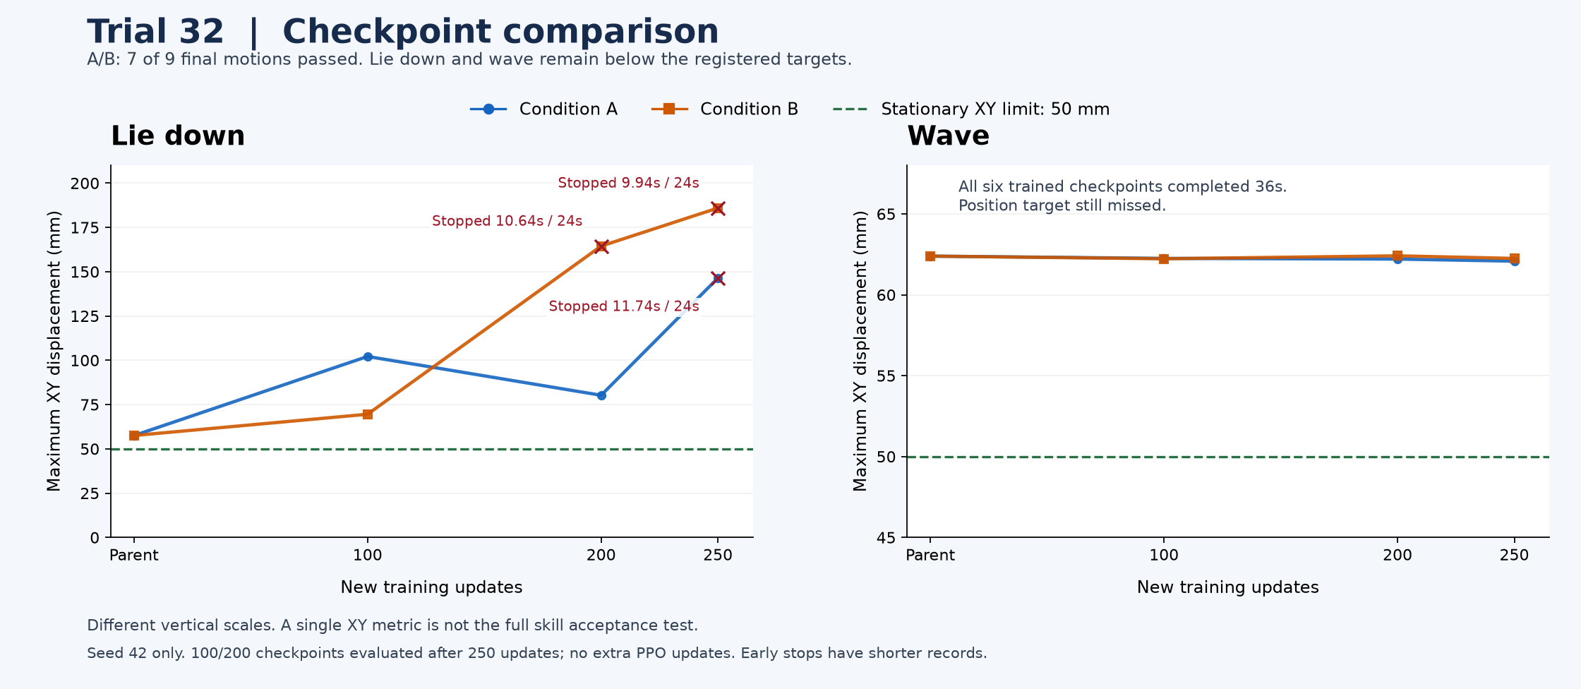
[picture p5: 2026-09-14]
docs/media/l27-checkpoint-comparison.png

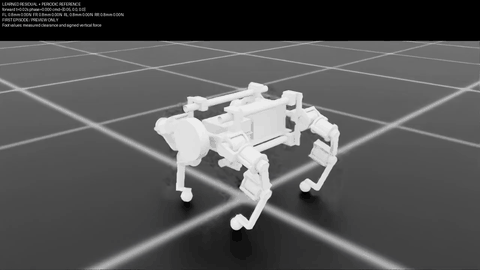
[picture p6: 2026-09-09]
docs/media/h04-forward.gif

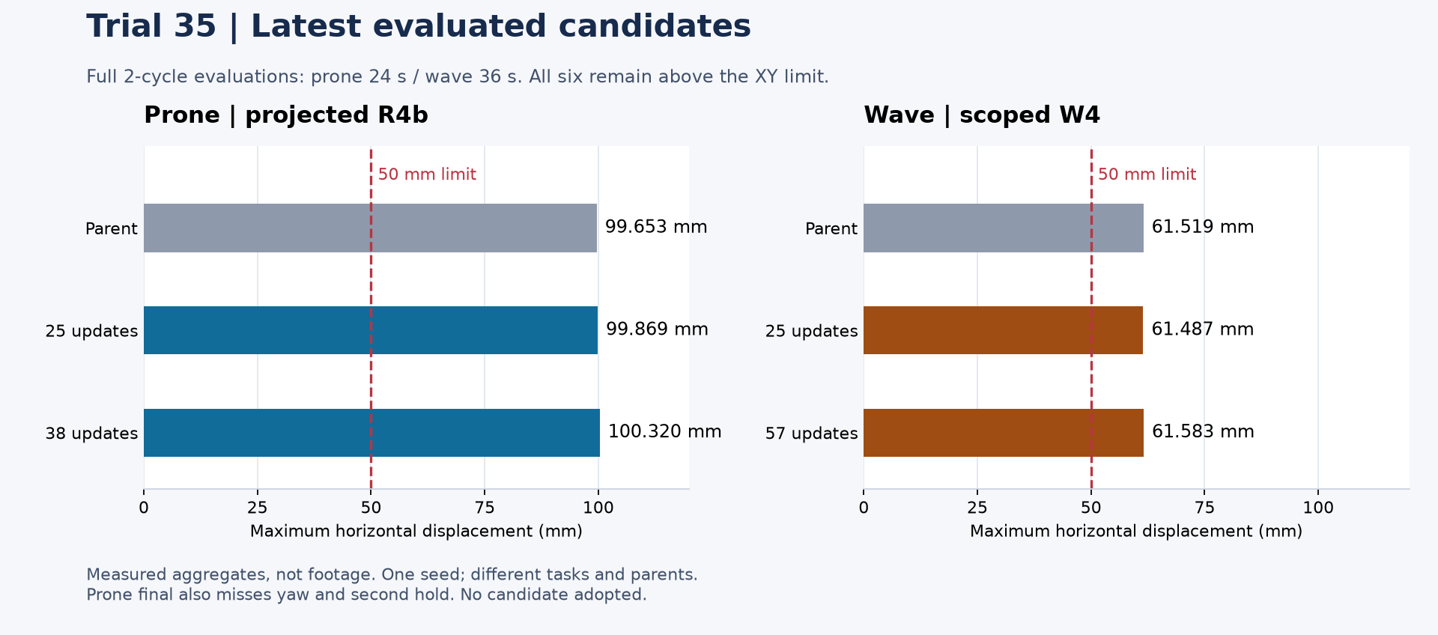
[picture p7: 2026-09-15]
docs/media/l30-checkpoint-comparison.png

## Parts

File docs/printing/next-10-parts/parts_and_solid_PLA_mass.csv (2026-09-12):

id | part_ja | color | quantity | plate | x_mm | y_mm | z_mm | solid_PLA_g_NOT_slicer_mass | file
B1_FL_base_mount | 左前 Body側モーターマウント | black | 1 | B | 162.0 | 88.9802 | 73.0 | 87.0837 | individual_parts/black/B1_FL_base_mount_mm.stl
B2_FL_hip_collar | 左前 股関節カラー | black | 1 | B | 56.0 | 67.9611 | 6.0 | 11.3086 | individual_parts/black/B2_FL_hip_collar_mm.stl
A1_FL_hip | 左前 股リンク | yellow | 1 | A | 55.9941 | 102.0 | 78.0 | 54.0751 | individual_parts/yellow/A1_FL_hip_mm.stl
A2_FL_thigh_collar | 左前 腿側カラー | yellow | 1 | A | 56.0 | 67.9611 | 6.0 | 11.0425 | individual_parts/yellow/A2_FL_thigh_collar_mm.stl
A3_FL_thigh | 左前 腿リンク | yellow | 1 | A | 66.0 | 163.9802 | 75.0 | 87.0706 | individual_parts/yellow/A3_FL_thigh_mm.stl
A4_FL_calf_collar | 左前 脛側カラー | yellow | 1 | A | 56.0 | 67.9611 | 6.0 | 11.0425 | individual_parts/yellow/A4_FL_calf_collar_mm.stl
A5_FL_calf | 左前 脛リンク | yellow | 1 | A | 31.999 | 122.0 | 53.0 | 63.7332 | individual_parts/yellow/A5_FL_calf_mm.stl
C1_face_support | 顔の背面支持台 | black | 1 | C | 104.0 | 103.9605 | 79.0 | 92.5891 | individual_parts/black/C1_face_support_mm.stl
B3_face_upper_clamp | 顔支持の上クランプ | black | 1 | B | 48.0 | 76.0 | 18.0 | 65.7587 | individual_parts/black/B3_face_upper_clamp_mm.stl
D1_recovery_handle | 回収取手 | yellow | 1 | D | 187.9602 | 85.5 | 24.0 | 220.076 | individual_parts/yellow/D1_recovery_handle_mm.stl

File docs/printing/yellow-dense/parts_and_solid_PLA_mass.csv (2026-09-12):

id | part_ja | plate | quantity | x_mm | y_mm | z_mm | solid_PLA_g_NOT_slicer_mass | previously_supplied | file
d20_long_-1_-1_1_lower | 上側D20カーボン管クランプ 下半分 | 1 | 1 | 40.961 | 22.0 | 12.75 | 8.8286 | False | individual_parts/d20_long_-1_-1_1_lower_mm.stl
d20_long_-1_-1_1_upper | 上側D20カーボン管クランプ 上半分 | 2 | 1 | 40.961 | 22.0 | 12.75 | 8.8286 | False | individual_parts/d20_long_-1_-1_1_upper_mm.stl
d20_long_-1_1_1_lower | 上側D20カーボン管クランプ 下半分 | 4 | 1 | 40.961 | 22.0 | 12.75 | 8.8286 | False | individual_parts/d20_long_-1_1_1_lower_mm.stl
d20_long_-1_1_1_upper | 上側D20カーボン管クランプ 上半分 | 4 | 1 | 40.961 | 22.0 | 12.75 | 8.8286 | False | individual_parts/d20_long_-1_1_1_upper_mm.stl
d20_long_1_-1_1_lower | 上側D20カーボン管クランプ 下半分 | 3 | 1 | 40.961 | 22.0 | 12.75 | 8.8286 | False | individual_parts/d20_long_1_-1_1_lower_mm.stl
d20_long_1_-1_1_upper | 上側D20カーボン管クランプ 上半分 | 3 | 1 | 40.961 | 22.0 | 12.75 | 8.8286 | False | individual_parts/d20_long_1_-1_1_upper_mm.stl
d20_long_1_1_1_lower | 上側D20カーボン管クランプ 下半分 | 3 | 1 | 40.961 | 22.0 | 12.75 | 8.8286 | False | individual_parts/d20_long_1_1_1_lower_mm.stl
d20_long_1_1_1_upper | 上側D20カーボン管クランプ 上半分 | 1 | 1 | 40.961 | 22.0 | 12.75 | 8.8286 | False | individual_parts/d20_long_1_1_1_upper_mm.stl
FL_hip_joint_part | 左前 股リンク | 1 | 1 | 55.994 | 102.0 | 78.0 | 54.0751 | True | individual_parts/FL_hip_joint_part_mm.stl
FL_thigh_front_collar | 左前 腿側カラー | 2 | 1 | 56.0 | 67.961 | 6.0 | 11.0425 | True | individual_parts/FL_thigh_front_collar_mm.stl
FL_thigh_joint_part | 左前 腿リンク | 3 | 1 | 66.0 | 163.98 | 75.0 | 87.0706 | True | individual_parts/FL_thigh_joint_part_mm.stl
FL_calf_front_collar | 左前 脛側カラー | 4 | 1 | 56.0 | 67.961 | 6.0 | 11.0425 | True | individual_parts/FL_calf_front_collar_mm.stl
FL_calf_joint_part | 左前 脛リンク | 3 | 1 | 31.999 | 122.0 | 53.0 | 63.7332 | True | individual_parts/FL_calf_joint_part_mm.stl
FR_hip_joint_part | 右前 股リンク | 1 | 1 | 55.994 | 102.0 | 78.0 | 54.0671 | False | individual_parts/FR_hip_joint_part_mm.stl
FR_thigh_front_collar | 右前 腿側カラー | 3 | 1 | 56.0 | 67.961 | 6.0 | 11.0425 | False | individual_parts/FR_thigh_front_collar_mm.stl
FR_thigh_joint_part | 右前 腿リンク | 1 | 1 | 66.0 | 163.98 | 75.0 | 87.0706 | False | individual_parts/FR_thigh_joint_part_mm.stl
FR_calf_front_collar | 右前 脛側カラー | 4 | 1 | 56.0 | 67.961 | 6.0 | 11.0425 | False | individual_parts/FR_calf_front_collar_mm.stl
FR_calf_joint_part | 右前 脛リンク | 3 | 1 | 31.999 | 122.0 | 53.0 | 63.7332 | False | individual_parts/FR_calf_joint_part_mm.stl
RL_hip_joint_part | 左後 股リンク | 4 | 1 | 55.994 | 102.0 | 78.0 | 54.0671 | False | individual_parts/RL_hip_joint_part_mm.stl
RL_thigh_front_collar | 左後 腿側カラー | 1 | 1 | 56.0 | 67.961 | 6.0 | 11.0425 | False | individual_parts/RL_thigh_front_collar_mm.stl
RL_thigh_joint_part | 左後 腿リンク | 3 | 1 | 66.0 | 163.98 | 75.0 | 87.0706 | False | individual_parts/RL_thigh_joint_part_mm.stl
RL_calf_front_collar | 左後 脛側カラー | 4 | 1 | 56.0 | 67.961 | 6.0 | 11.0425 | False | individual_parts/RL_calf_front_collar_mm.stl
RL_calf_joint_part | 左後 脛リンク | 2 | 1 | 31.999 | 122.0 | 53.0 | 63.7332 | False | individual_parts/RL_calf_joint_part_mm.stl
RR_hip_joint_part | 右後 股リンク | 2 | 1 | 55.994 | 102.0 | 78.0 | 54.0751 | False | individual_parts/RR_hip_joint_part_mm.stl
RR_thigh_front_collar | 右後 腿側カラー | 1 | 1 | 56.0 | 67.961 | 6.0 | 11.0425 | False | individual_parts/RR_thigh_front_collar_mm.stl
RR_thigh_joint_part | 右後 腿リンク | 2 | 1 | 66.0 | 163.98 | 75.0 | 87.0706 | False | individual_parts/RR_thigh_joint_part_mm.stl
RR_calf_front_collar | 右後 脛側カラー | 2 | 1 | 56.0 | 67.961 | 6.0 | 11.0425 | False | individual_parts/RR_calf_front_collar_mm.stl
RR_calf_joint_part | 右後 脛リンク | 4 | 1 | 31.999 | 122.0 | 53.0 | 63.7332 | False | individual_parts/RR_calf_joint_part_mm.stl

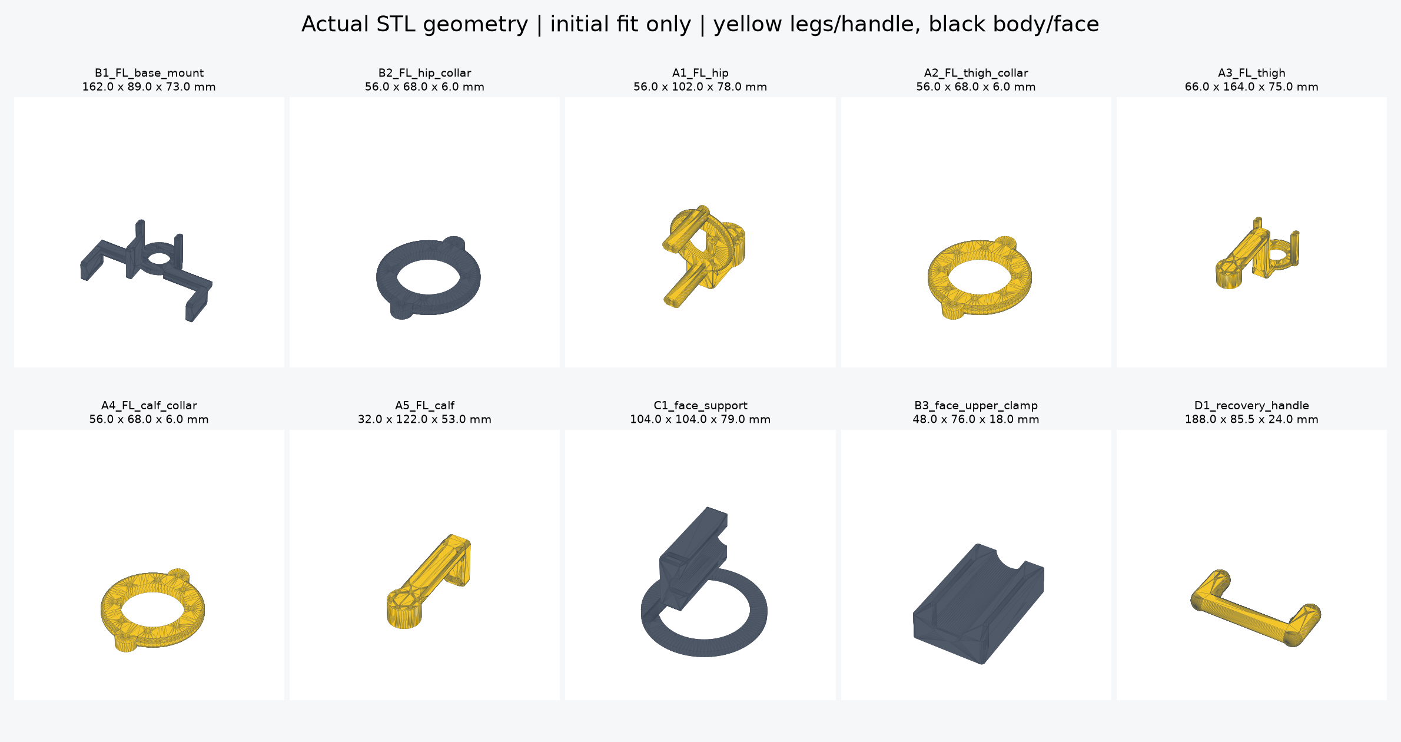
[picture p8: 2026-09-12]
docs/printing/next-10-parts/individual_parts_preview.png

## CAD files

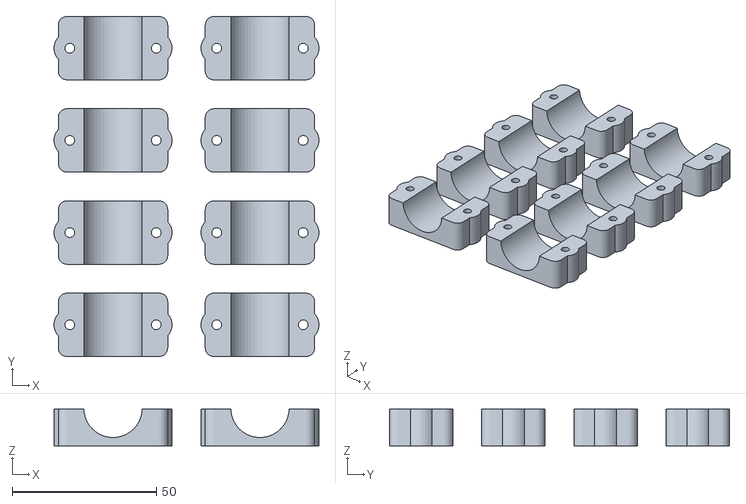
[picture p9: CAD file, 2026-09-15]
docs/printing/common-deck-k1max-r2/optional_plates/CLAMPS_ONLY_8parts_black_mm.stl
92.0 x 118.0 x 12.8

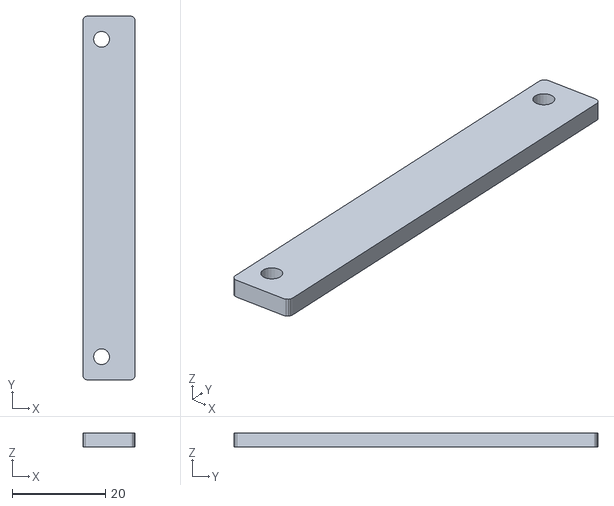
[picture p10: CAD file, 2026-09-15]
docs/printing/common-deck-k1max-r2/printable_mm/B27_jetson_edge_retainer_rear_mm.stl
11.2 x 78.0 x 3.00

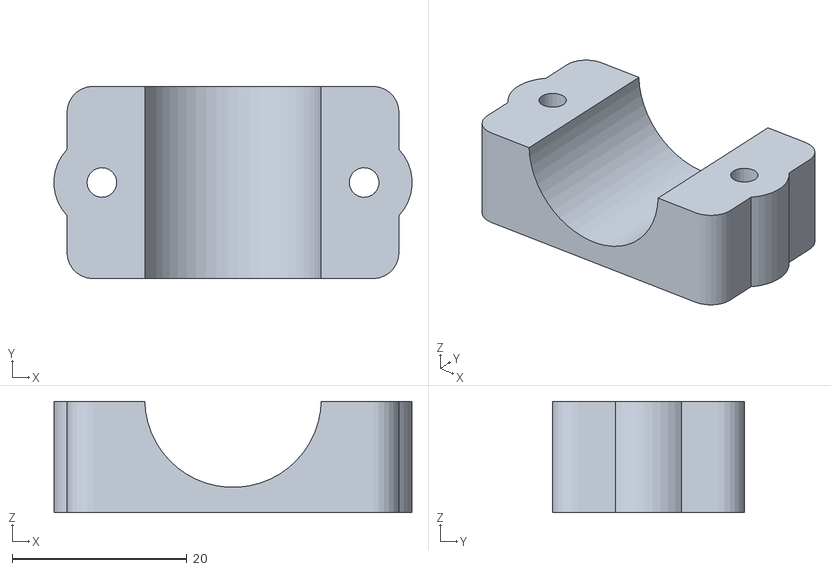
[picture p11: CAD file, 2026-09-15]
docs/printing/common-deck-k1max-r2/printable_mm/lower_pole_clamps/B22_d20_long_1_-1_-1_upper_mm.stl
41.0 x 22.0 x 12.8

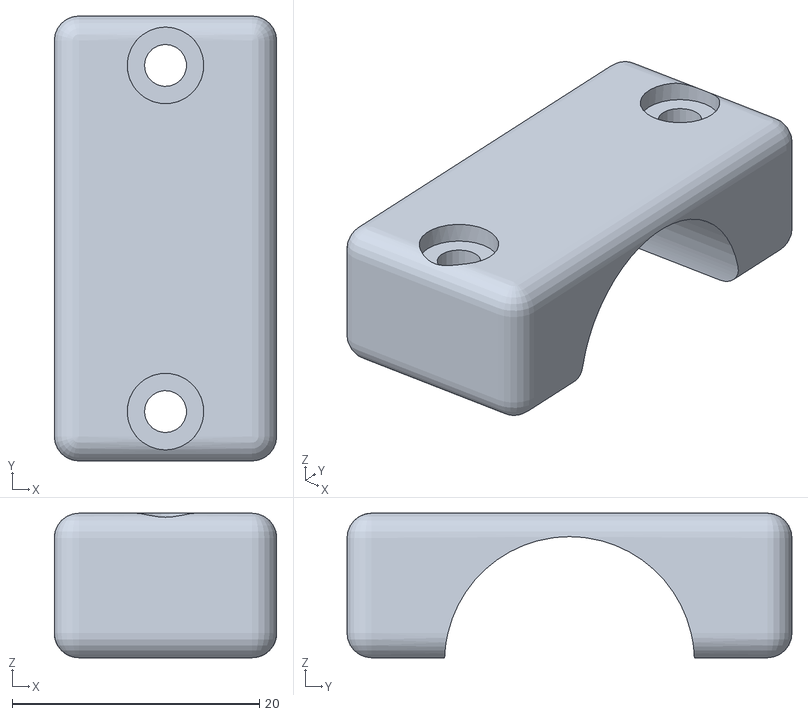
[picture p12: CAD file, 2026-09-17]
docs/printing/current/black/B36_pla_prone_skid_cap_right_front_mm.stl
18.0 x 36.0 x 11.7

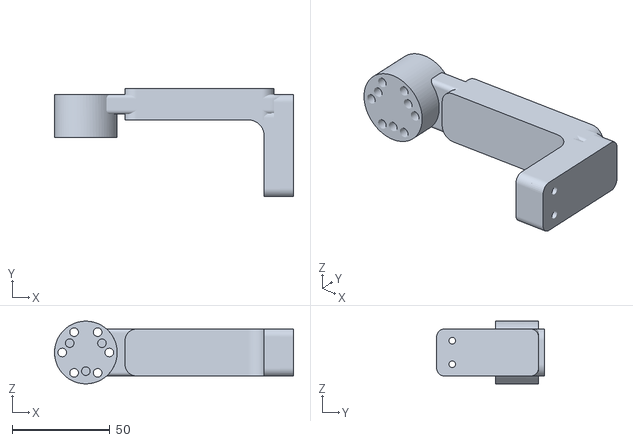
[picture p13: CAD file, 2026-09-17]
docs/printing/current/yellow/Y26_FL_calf_joint_part_reinforced_mm.stl
122.0 x 55.0 x 32.0

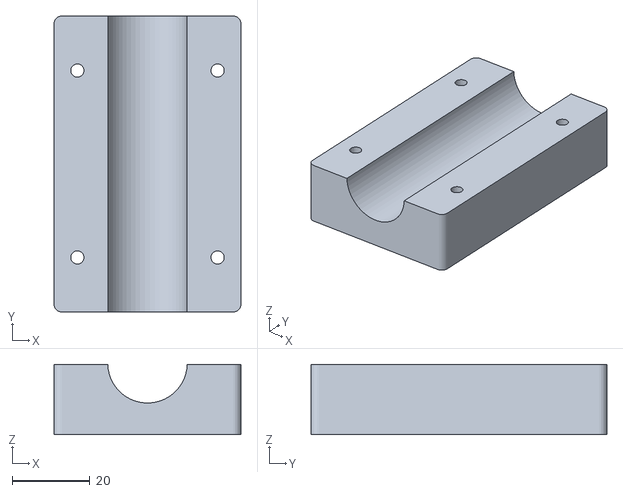
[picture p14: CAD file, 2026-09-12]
docs/printing/next-10-parts/individual_parts/black/B3_face_upper_clamp_mm.stl
48.0 x 76.0 x 18.0

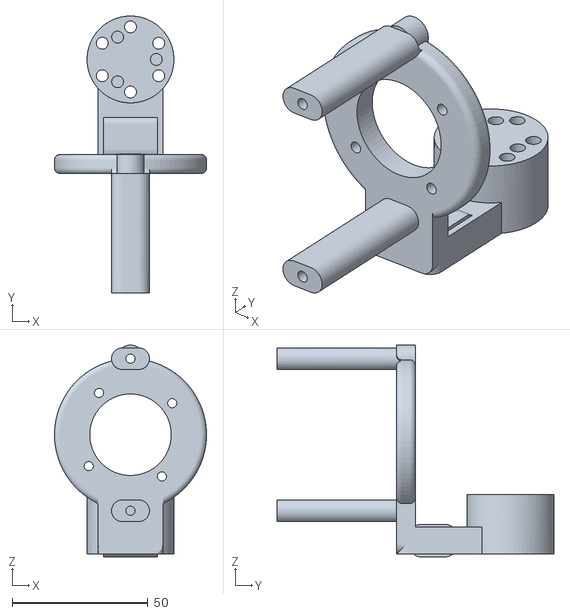
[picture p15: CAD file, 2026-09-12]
docs/printing/next-10-parts/individual_parts/yellow/A1_FL_hip_mm.stl
56.0 x 102.0 x 78.0

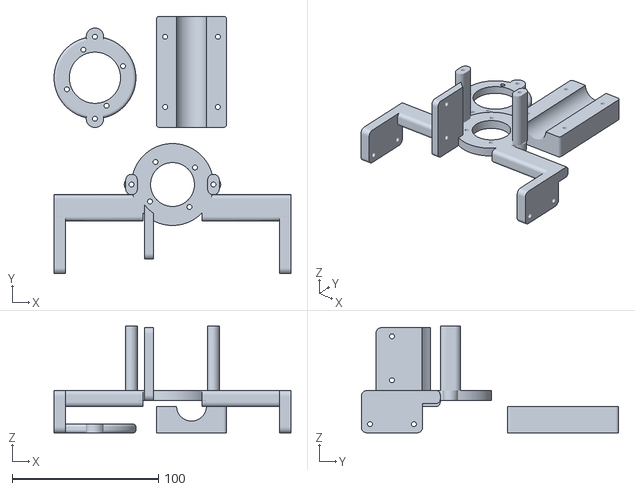
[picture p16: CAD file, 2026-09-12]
docs/printing/next-10-parts/PLATE_B_black_FL_base_and_face_clamp_3parts_mm.stl
162.0 x 176.0 x 73.0

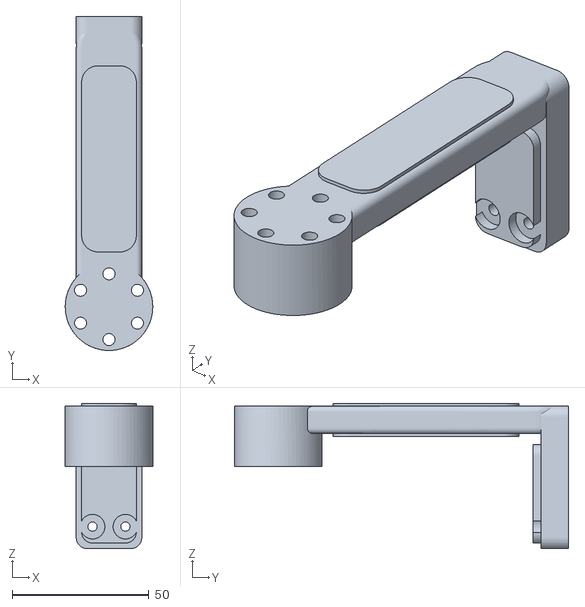
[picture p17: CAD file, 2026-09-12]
docs/printing/yellow-dense/individual_parts/FL_calf_joint_part_mm.stl
32.0 x 122.0 x 53.0

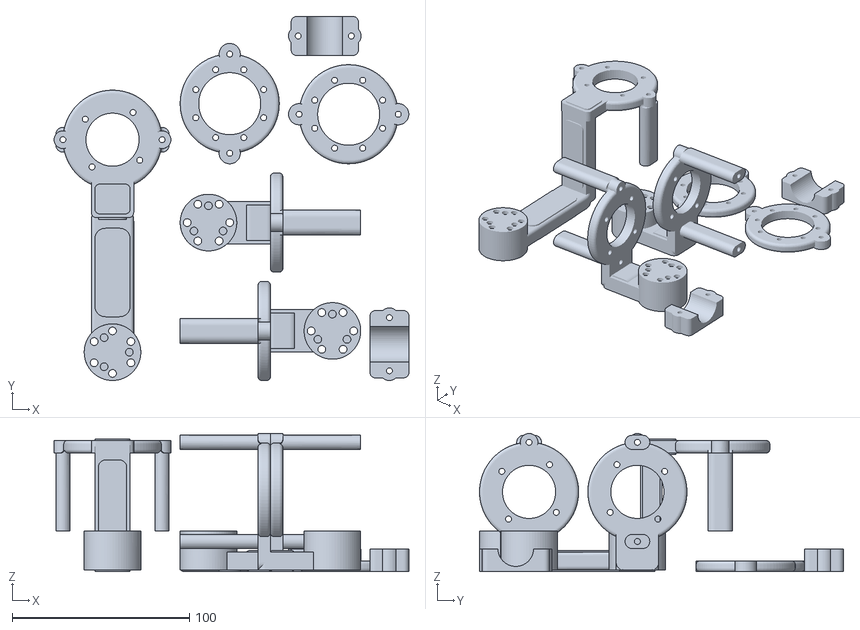
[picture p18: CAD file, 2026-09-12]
docs/printing/yellow-dense/PLATE_01_yellow_7parts_mm.stl
200.4 x 205.6 x 78.0

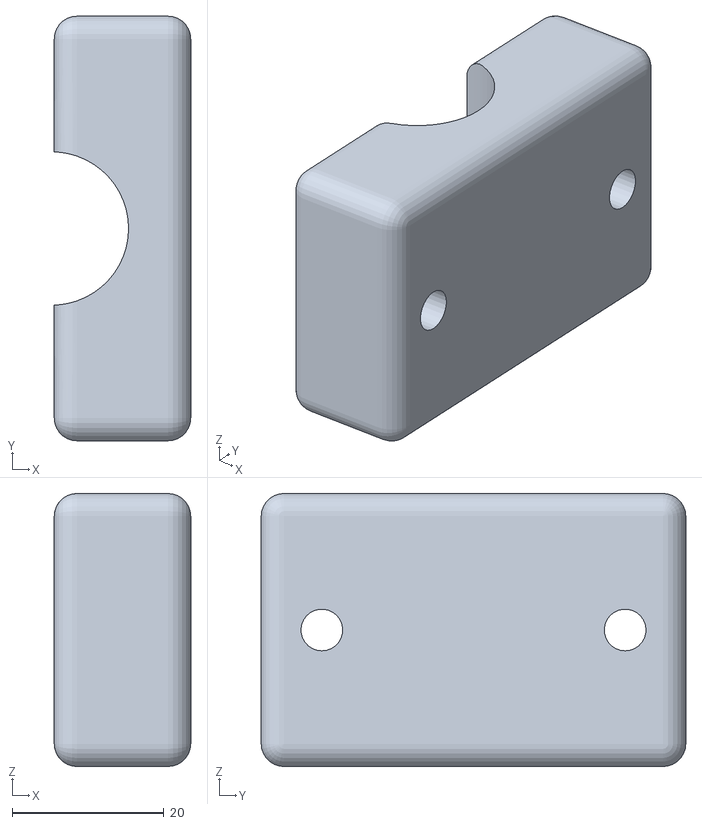
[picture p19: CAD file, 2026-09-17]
docs/printing/current/yellow/Y17_pla_rail_clamp_front_right_lower_mm.stl
18.0 x 56.0 x 36.0

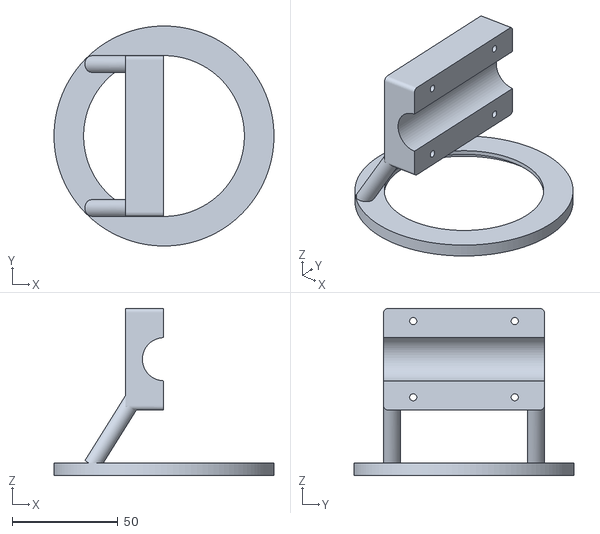
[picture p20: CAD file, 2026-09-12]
docs/printing/next-10-parts/individual_parts/black/C1_face_support_mm.stl
104.0 x 104.0 x 79.0

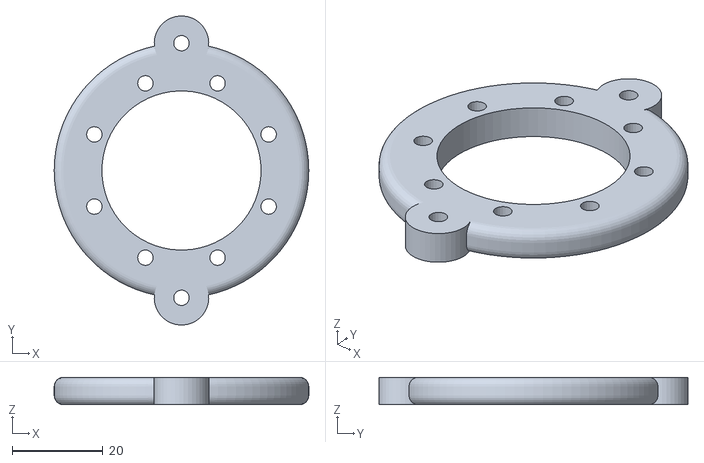
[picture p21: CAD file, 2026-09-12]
docs/printing/next-10-parts/individual_parts/yellow/A2_FL_thigh_collar_mm.stl
56.0 x 68.0 x 6.00

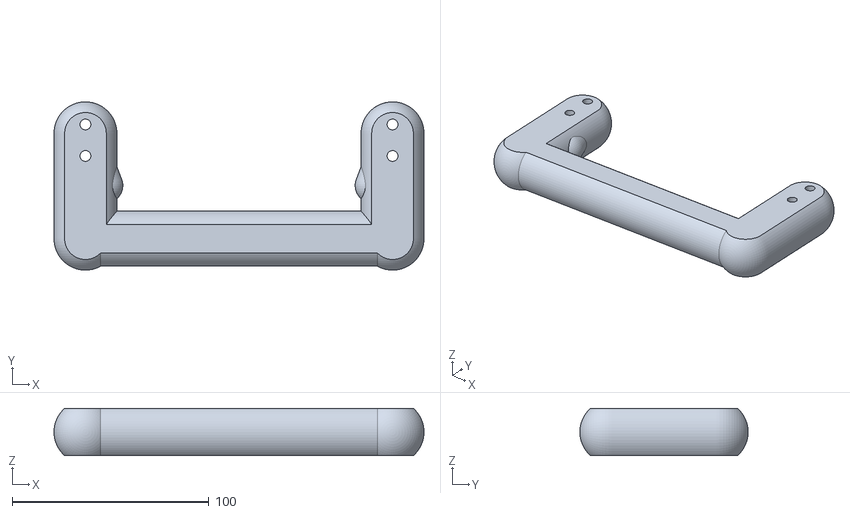
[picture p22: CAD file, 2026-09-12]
docs/printing/next-10-parts/PLATE_D_yellow_handle_1part_mm.stl
188.0 x 85.5 x 24.0

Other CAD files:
docs/printing/common-deck-k1max-r2/printable_mm/B26_jetson_edge_retainer_front_mm.stl
docs/printing/common-deck-k1max-r2/printable_mm/lower_pole_clamps/B17_d20_long_-1_-1_-1_lower_mm.stl
docs/printing/current/black/B34_pla_prone_skid_cap_left_front_mm.stl
docs/printing/common-deck-k1max-r2/printable_mm/common_equipment_plate_K1Max_r2_mm.stl
docs/printing/common-deck-k1max-r2/printable_mm/lower_pole_clamps/B18_d20_long_-1_-1_-1_upper_mm.stl
docs/printing/common-deck-k1max-r2/printable_mm/lower_pole_clamps/B19_d20_long_-1_1_-1_lower_mm.stl
docs/printing/common-deck-k1max-r2/printable_mm/lower_pole_clamps/B20_d20_long_-1_1_-1_upper_mm.stl
docs/printing/common-deck-k1max-r2/printable_mm/lower_pole_clamps/B21_d20_long_1_-1_-1_lower_mm.stl
docs/printing/common-deck-k1max-r2/printable_mm/lower_pole_clamps/B23_d20_long_1_1_-1_lower_mm.stl
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

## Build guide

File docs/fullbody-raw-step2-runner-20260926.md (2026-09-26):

# 全12軸 raw 最大2°診断ランナー：実装状態

状態: **無駆動試験は完走。最大2°の駆動試験はID7の2.5°逸脱で約7.7秒後に中断し、全12軸STOPを確認。** 操作者は動きが見え、異常なしと確認した。このランナーは立位や学習済みモデルの制御を行わない。[実測値とログSHA](../evidence/fullbody-step2-active-20260926.json)

`runtime/singularitydog_hw/rs05_fullbody_step2.py` は、現位置から全12軸を明示した raw 回転方向に最大2°動かす有限試験用である。両バスを別ワーカーで扱い、50 ms 周期で8秒の五次曲線ランプと1秒の終点観測を実行して、各バスの6軸へSTOPを試みる。ID4・ID10はKp4、ほか10軸はKp3、Kd0.15、速度・トルク目標は0。各軸の指令は予定フレームとバイト単位で照合する。通信欠落、故障、古い返信、位置差、速度・トルク監視値、周期期限の逸脱では両バスが中断してSTOPへ進む。

無駆動専用パッケージは `/private/tmp/fabo-postboot-20260925/fullbody-step2-disabled-20260926-r2` に生成した。元のr17凍結パッケージ、全12軸保持試験の実summary、`fullbody-hold-20260926.json`、raw 2°オフライン候補のSHA連鎖を照合し、146ファイルをpinしている。ラッパーは `--preflight-only` 以外の実行モードを持たず、UART直前でもEnableと非ゼロゲインを拒否する。これを使う場合も転送・実行時のbootと機体状態は別途確認する。

その無駆動実機試験は両バス各20周期を完了し、全12軸STOP、Enableなし、非ゼロゲインなしを確認した。summary SHA256は `3d9a4af736e9978816fc1abe189c17de695fbd310516ec7fe3937fd1889ca333`、events SHA256は `e0ebcab3a219fa547990163b1a51816e9bd3205fb4064e98e270a47ea1d71c73`。

駆動用の**raw 2°診断だけ**に限定した凍結パッケージは `/private/tmp/fabo-postboot-20260925/fullbody-step2-active-20260926-r2` に作成・転送し、実機で一度だけ試した。164ファイルをpinし、実機無駆動試験のsummary/eventsと同一bootの全12台UIDを照合する。UART直前の `Step2PacketPort` は各バス180周期×6軸の順序とバイト列を照合し、STOP後の追加駆動・第181周期・変更されたゲインや目標角を拒否する。旧raw角は目標に使わない。モデル校正済みや立位達成とは扱わない。

実行ログでは前後各154周期が完了し、次の右後ID7返信が開始位置から+2.6155°に達したため2.5°の逸脱監視で中断した。ID7への指令は約+1.999°で跳んでおらず、直前約0.2秒の実位置が急に追い付いた。最後の完全返信時点でID2は+0.176°、ID6は−0.110°、ID12は+0.132°にとどまり、約2°の指令への追従が不足した。ID7の停止幅だけを緩めても、全軸の終端追従条件は通らない。次はID7の機械的な遊び・負荷・支えとの関係、遅い軸の必要トルクを分けて調べる。現試験を自動再試行しない。

駆動前後の独立レビューでは、少なくとも次を確認する。

1. 当日bootの全12台UID、FW 0.5.0.13、全軸STOPを確認済みの保持試験結果、その実ファイルのSHA256を検証する。
2. raw 12方向・始点を現機体で測り直す。旧bootの角度・モデルoffsetは一切使わず、当日bootのType17/Type2と静止窓の一致を確認する。開始時の実測値とレビュー値の差は各軸0.5°以内とする。
3. 胴体の支持、四脚と配線の軌道全域の離隔、手離し、40Vを即時Offできる状態を試験直前に確認する。
4. 固定ファイルのSHA256を全件照合し、`ActivePort.write`相当の最下層ゲートで、前後2バスそれぞれ180回×6軸の指令順序・exact-wire・Enable後限定・STOP許可を照合する。ソースのレビュー用フラグだけで出力を認めない。

現時点の[オフライン候補](../evidence/fullbody-raw-step2-offline-20260926.json)は `output_allowed=false` で、校正・機械掃引が未確認。これをそのまま実行許可には使えない。ランナーの戻り値も、試験が完走しても `standing_allowed=false`、`learned_policy_allowed=false` とする。

検証: `PYTHONPATH=runtime:runtime/tests python3 -B -m unittest test_rs05_step2_packet_gate test_rs05_fullbody_step2 test_rs05_fullbody_hold test_rs05_leg_settled -q` は53件成功。凍結パッケージ内の同じ53件も成功。仮想UARTで通常完走、レビュー不一致、始点ずれ、改変フレーム、通信・停止失敗を確認した。

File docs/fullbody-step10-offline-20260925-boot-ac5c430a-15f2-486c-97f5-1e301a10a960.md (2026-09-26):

# 12軸・最大10°立位方向のオフライン幾何候補 — 2026-09-25

**状態: OFFLINE_GEOMETRY_ONLY／未実行。** 起動ID `ac5c430a-15f2-486c-97f5-1e301a10a960` の無駆動読取り値から計算した候補であり、モーターへ10°の目標値を送っていない。読取りは `READ_ONLY_COMPLETE`、全12台のUIDが一致し、モーター有効化は0件だった。

[機械可読の角度・足先変位とソースSHA-256](../evidence/fullbody-step10-offline-20260925-boot-ac5c430a-15f2-486c-97f5-1e301a10a960.json)

開始角は保存時点の値で、実行直前の現在角度を示さない。校正オフセットと公称立位は候補であり、絶対角度精度は未確認。

|ID|脚/関節|現在raw rad|終点候補raw rad|raw差°|終点モデル°|モデル範囲|r13→r14始点差°|
|---:|---|---:|---:|---:|---:|---|---:|
|1|FR/calf|5.839172|6.013705|+10.00|-61.40|内|+0.00|
|2|FR/thigh|4.533754|4.708287|+10.00|+10.67|内|+0.00|
|3|FR/hip|5.511940|5.686472|+10.00|+31.75|外 3.10°|+0.04|
|4|FL/calf|5.470472|5.295939|-10.00|-55.05|内|-2.02|
|5|FL/thigh|3.404843|3.230310|-10.00|+14.75|内|+0.01|
|6|FL/hip|5.553209|5.378676|-10.00|-22.68|内|+0.01|
|7|RR/calf|4.653257|4.827790|+10.00|-77.28|内|-0.01|
|8|RR/thigh|6.567615|6.742148|+10.00|+21.71|内|+0.02|
|9|RR/hip|6.405310|6.230777|-10.00|+36.79|外 8.14°|-0.07|
|10|RL/calf|3.848065|4.022598|+10.00|-105.84|内|+0.06|
|11|RL/thigh|0.603745|0.429212|-10.00|+10.00|内|+0.01|
|12|RL/hip|1.017177|1.191710|+10.00|-20.23|内|-0.04|

終点モデル範囲外: ID3（上限超過3.10°）、ID9（上限超過8.14°）。これらは公称立位へ近づく方向だが、既存のモデル範囲ゲートを満たさない。rawの2π境界横断: [9]。後者は角度をwrapせず連続値として扱う必要がある。

足先球中心の胴体固定座標での変位（mm、x前/y左/z上）:

|脚|x|y|z|
|---|---:|---:|---:|
|FR|-41.2|-10.9|-36.9|
|FL|-47.2|+21.8|-30.9|
|RR|-37.3|-7.5|-34.4|
|RL|-9.5|+2.2|-30.8|

4脚とも足先中心が約31〜37mm下がる。現在位置は実行時点で変わり得るため再読取りが必要。足球半径・リンク・ケーブル・支持台の余裕、自己干渉、モーター負荷は未検証。前回の全12軸保持はID4の約1.67°追従差で中断している。

前回r13からの始点変化はID4が−2.02°で最大だった。r13の全12軸現在位置保持はID4の最終追従差約1.67°で停止しており、この幾何計算は追従・停止・立位成立を証明しない。

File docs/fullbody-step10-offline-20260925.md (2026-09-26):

# 全12軸・最大10°の同時試験案（無駆動）

直近の現起動試験 `Fullbody-current-hold-boot4aaf-r13` は、約4秒で左前脚ID4の固定目標との差が約1.67°になり、5秒保持を完了せずに停止した。12台のSTOP返信と操作者の異常なしは確認したが、この結果を10°の同時駆動許可には使わない。

現状は[オフライン軌道と監視条件](../runtime/singularitydog_hw/fullbody_step10_plan.py)のみ実装した。12台共通の8秒quinticランプと1秒終端保持、50ms周期・180標本、開始位置から最大10°、各軸の生角度方向を明示する形式である。軌道を作るだけでCANへは送らない。推定方向を自動採用しない。方向が未確定なら計画を作らない。

実機用ランナーを実装・適用する前に、ID4の取付・リンクの遊び・接触を脱力状態で点検し、現在の起動で全12軸の5秒保持を通過させる。さらに12軸の個体ID、移動方向、各リンクの通路、支持台からの離隔、手離し、即時40V Offを確かめる。前後2バスの制御処理では、毎周期全12台の新しい返信を得て各軸の追従差・トルク・故障・速度・温度・通信鮮度を監視し、どれか一つでも外れたら両バスの全12台へSTOPを試みる。STOP返信未確認なら電源遮断を依頼する。ソフト監視値はトルクの物理的な上限を保証しない。

旧r13姿勢の幾何計算から得た仮の立位方向は、ID1から順に `+,+,+,-,-,-,+,+,-,+,-,+` だが、これは現物で確認した生角度方向ではない。4脚を一律に10°動かしても立位にはならず、旧始点から10°だけではID3/9は学習モデルの可動域へ入らない。足先は約31〜37mm下がる計算のため、床・支持台との実際の離隔が必要になる。

この資料とコードは立位・学習済みモデルの適用許可や、実機での追従成功を示さない。

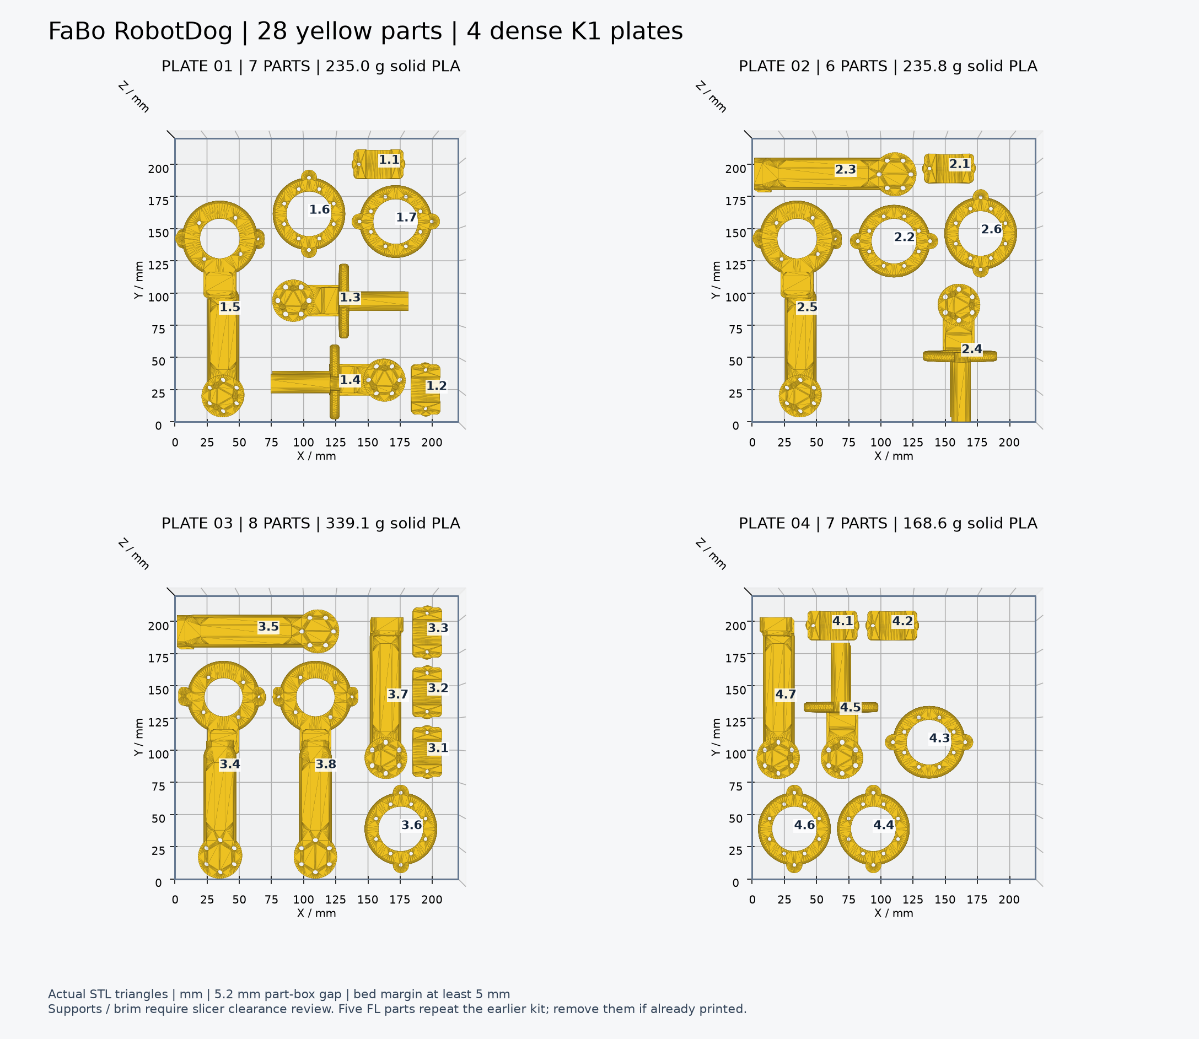
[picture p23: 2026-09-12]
docs/printing/yellow-dense/print_plate_top_view.png

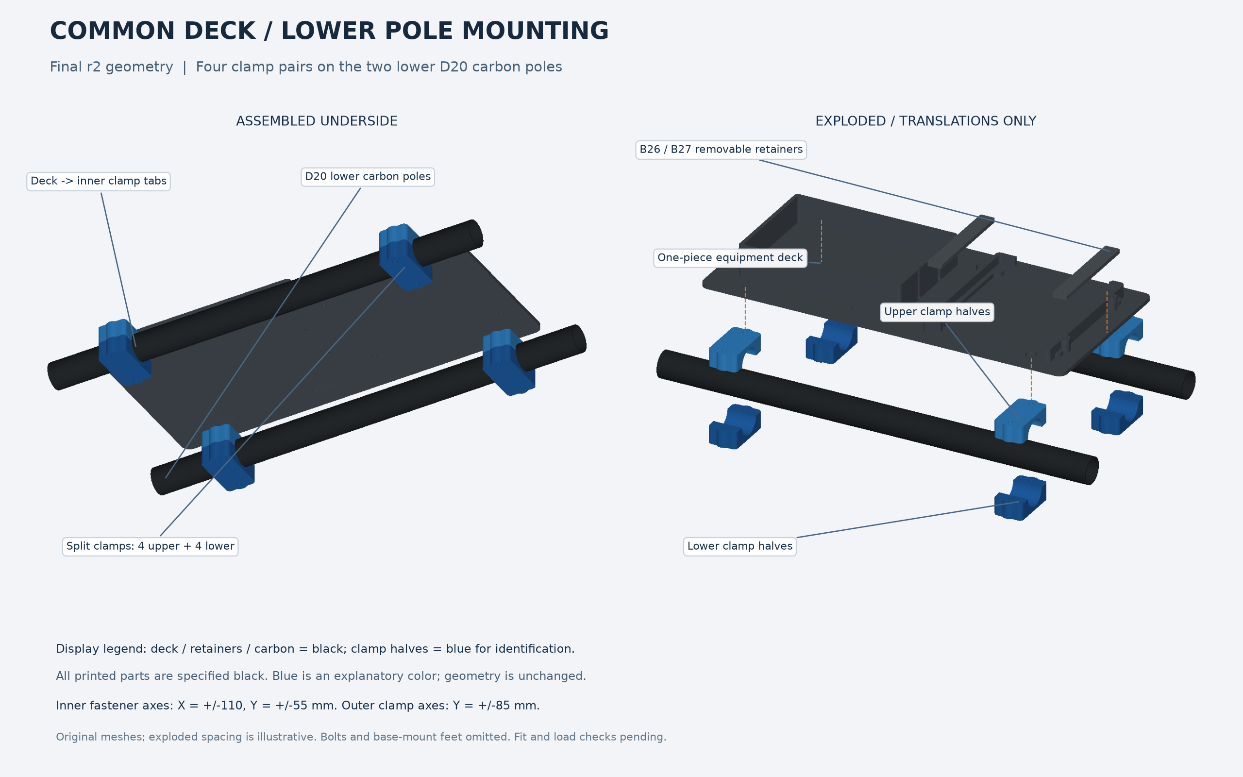
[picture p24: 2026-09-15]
docs/printing/common-deck-k1max-r2/previews/common_plate_mounting_underside_exploded.png

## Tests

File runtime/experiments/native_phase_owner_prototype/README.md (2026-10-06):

# Fake native phase owners

This complete, isolated **file/pipe-only prototype** tests a different handoff
structure: two persistent pthread owners publish fixed native phase slots, and a
coordinator collects both buses through a bounded CDLL call. It does not open or
configure any serial/CAN/IMU device, link `sd_exchange`, load a model, select a
production runtime, or implement a motor frame. The 32-byte `SDFAKEQ1` /
`SDFKREP1` packets are an explicitly separate fake protocol.

Each generation has one absolute native `CLOCK_MONOTONIC` deadline of at most
20 ms and three fixed slots per bus. Each owner publishes feedback, notifies the
native condition, then progresses to voltage without a Python Future. The
coordinator must collect and acknowledge both same-generation pairs, and
explicitly submit the fake `STOP_ONLY` phase. Slots cannot be overwritten until
all six are acknowledged. Generations strictly increase; each owner retains its
last finish time and applies a 900 µs fake inter-stage gap. Failed packets or
generations are not retried. A bounded fake exchange may continue partial
reads/writes and repeat EINTR/EAGAIN operations within that same packet; this is
not the real transport's transient-count or partial-write contract.
The real 26-request schedule, window-three behavior, motor feedback semantics,
boot identity checks and STOP confirmation are **not** reproduced or qualified.

`collect` requests at most 200 µs per call, records the actual monotonic return
observation, and checks native errors before readiness/timeouts. Linux uses
`pthread_condattr_setclock(CLOCK_MONOTONIC)` and `ppoll`; macOS uses relative
`pthread_cond_timedwait_relative_np` and `select` derived from fresh monotonic
remaining time. No realtime-absolute deadline is substituted. An OS scheduling
stall can still make an observed return late. This is not a proof that runtime
boot-guard checkpoints, main-thread GIL reacquisition, IMU work or Python
semantic validation have become bounded or unnecessary.

Native errors poison the entire session. Cancellation is sticky and wakes
native waiters; a later timeout/cancellation does not overwrite the first native
error. A copied snapshot must match its native slot byte for byte before an
acknowledgement. Partial or absent replies retain their actual byte counts and
cannot become completed rows. Ready/consumed masks distinguish missing slots
from saved rows; unready all-zero scratch is not evidence of success.

The native API accepts distinct nonblocking FIFO pipe descriptors. The supplied
executable example and tests create private **anonymous pipes**, but `S_ISFIFO`
alone also accepts named FIFOs. No device descriptors are accepted. The API
captures dev/inode/access/nonblocking identity and duplicates descriptors with
close-on-exec. It never sets caller descriptor flags or closes caller-owned FDs.
macOS may add its kernel `FWRITTEN` observation after a write; caller-settable
access/nonblocking/append flags remain unchanged. Duplicating a pipe does not
prove the existing real-transport `Session` FD identity/boot guard contract.

The coordinator is a single creating thread with nonreentrant entry checks.
`Owners(bindings)` allocates no native resources. The caller retains that object
before calling `start(fds)`. Native creation publishes its token into the object's
preallocated caller-owned cell before returning. An interruption after creation
therefore leaves a reachable token for the caller's `finally` cleanup, including
retry if cleanup fails; there is no pointer-return creation factory. Callers that
discard the object or fail to attempt cleanup are outside this managed protocol.
Cancellation can come from another thread. Native handles are nonreused opaque
registry tokens, not addresses: the registry serializes lookup/deletion, and an
old token is rejected even if Python is interrupted after native close but
before clearing its wrapper field. Such a cleanup retry reports **unknown
original cleanup evidence**, rather than inventing a restored proof. The Python
lifetime lock additionally serializes cancellation versus close. The registry
also serializes prototype C entries; this is an explicit experimental design
tradeoff, not a performance claim.

Close marks cancellation before waiting for in-flight owners, observes their
termination, joins them, then closes owned duplicates and releases state. Linux
uses bounded try-join; macOS has no timed pthread join, so it joins only after
owner exit is observed and reports any late completion instead of bounded
success. Cleanup failure retains the session for a safe retry. No worker is
detached, and state is not freed while an owner can use it. Fake responder threads
are independently joined even when native cleanup or a Python interrupt fails.
The tested interruptions are the native-create/native-close return boundaries;
this is not a blanket asynchronous-exception guarantee during Python fixture
construction or file-descriptor creation.

Default CLI is PLAN: it reads source metadata and writes a fresh result outside
Git, without compiling/loading a library or opening pipes. Explicit file-only
execution builds one private library, verifies its source/binary/build record
and exact structure ABI, and runs two fake generations. Outputs cannot overwrite
or follow symlinks. All live qualification and performance claims remain false.

```sh
PYTHONDONTWRITEBYTECODE=1 PYTHONPATH=runtime/experiments \
  python3 -B -m unittest native_phase_owner_prototype.test_prototype -q

PYTHONDONTWRITEBYTECODE=1 PYTHONPATH=runtime/experiments \
  python3 -B -m native_phase_owner_prototype.prototype \
  --execute-file-only --output /absolute/fresh/private/prototype.json
```

Future real integration needs a separate source/ABI/artifact review of unchanged
`sd_exchange`, existing session/boot guards, exact request pacing, voltage
validation, snapshots, native error handling, stop ambiguity and cleanup. This
prototype does not establish core parity, explain an 866.646 µs delay, or prove
that removing Future publication improves the real loop.

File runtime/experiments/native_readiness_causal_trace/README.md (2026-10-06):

# Isolated readiness timing observations

This source-only prototype investigates the saved R37 diagnostic failure. Its
last native reply preceded the 20 ms deadline, but Python observed the final
wait callback return after the deadline. Earlier in that same cycle, the saved
voltage validation end preceded the main voltage join by about 867 microseconds.
These observations do not identify GIL, scheduling or device latency as a cause.

The command line prints a file-only plan. It has no execute/build/device option.
No production benchmark, controller, transport, profile or caller is changed.
`build_traced_helper()` verifies the fixed K37 source SHA and imported function
bytecode, then constructs a separate helper. With `trace=None`, it delegates
directly to the original function without extra trace clocks or callbacks.

An explicitly supplied `FixedReadinessTrace` records fixed-size numeric rows:

- readiness/error checking and boot/cancellation guard wall and thread CPU times;
- planned native wake, the native callback's returned `woke_ns`, and the existing
  Python return clock;
- the unchanged decision and completion clocks;
- one registration and completion-callback observation per owner Future,
  including the separate voltage-validation Future when present.

The completion callback runs **after** internal Future completion. It is an
upper-bound observation, not the exact publication time, native exchange end,
or on-wire arrival. A callback registered on an already-done Future is explicitly
marked. The returned native time also requires the original verified native
waiter binding; the experiment alone does not authenticate a callback's claim.
Callback thread CPU time belongs to the thread executing that callback: the
registering thread for an already-done Future, or its completing worker. It is
not authenticated native-owner CPU time and must not be subtracted from a
different thread's clock.

Rows and callback closures are allocated before polling. No per-poll list,
dictionary or I/O is added. Python clocks and numeric bookkeeping still have a
cost, so this is not claimed to be allocation-free or free of measurement
overhead. Capacity is bounded; overflow and measurement errors invalidate trace
completeness without extending deadlines, hiding original errors or replacing
results. Source sample times and native dispatch deadlines are untouched.

Export only after the helper has finished and every original owner has settled;
normal owner cleanup remains the caller's responsibility. Returned JSON is a
copy and grants neither timing qualification nor motor-output authority.

Before a separately approved disabled diagnostic integrates this prototype:
bind source/library/ABI and cycle/phase/owner identities, measure added trace
overhead against an uninstrumented run, preserve original result/error/restore
artifacts, and separately identify worker-return versus Future callback times.
No such integration or target measurement has been performed here.

Tests use synthetic clocks, Futures and subprocesses that can only print PLAN
or reject unsupported CLI arguments. They reproduce timely completion, observed
return overshoot, guard delays, error/cancellation precedence, overflow, source
mutation, and default delegation without CAN/IMU/native library/model access.

## Separate collector and source bundle

`generate.py`, `collector_support.py`, and `child_runner.py` provide a reusable
integration **outside** the frozen benchmark. Generation is file-only; it does
not import the generated benchmark or launch anything. It requires the exact K37
benchmark bytes. Only `collect` and `main` change in the generated copy. Every
replacement is inverted and the complete original bytes and AST must match.
Structural checks use exceptions and remain active under `python -O`.

Supply an absolute fresh private output directory and the intended target kit
path. The latter is a declaration about the target host, not a local filesystem
check; the child verifies all 650 target kit members before importing the copy.
For example, after setting `BASELINE`, `KIT`, and `OUT` to the intended paths:

```sh
python3 -B runtime/experiments/native_readiness_causal_trace/generate.py \
  --baseline "$BASELINE" --kit-path "$KIT" --output "$OUT"
```

This writes four pinned source members plus `manifest.json` and a derivation
receipt. A source-sealed scoped launcher can also be derived with
`--launcher-template "$ORIGINAL_R37_LAUNCHER" --target-bundle "$TARGET_BUNDLE"`.
The exact original outer-launcher SHA is required. Its boot, power, calibration,
UID, native build/ABI, model, source-test and reversible performance-scope checks
remain. Inverse byte/AST validation proves that all declared launcher changes
can be removed to recover that exact original. Target source checks and current
physical conditions must still be reviewed before any target execution.

The derived scoped launcher's default is PLAN, with required `--phase voltage`
or `--phase output` and default `--cycles 5`. It permits at most 50 cycles. It
retains STOP-only, gap 900 microseconds, window 3, 20 ms deadlines, and the
existing source-bound limits. `--execute` is an explicit future diagnostic
choice; **no generated bundle or launcher has been deployed or executed on a
robot in this source task**. PLAN performs file checks and imports the copied
module but does not open hardware or change the Python switch interval. The
child executes verified source bytes rather than a stale bytecode cache.
All copied and derived command-line parsers reject abbreviated options, so
`--exec` cannot bypass the child's exact `--execute` scope selection.

Only the selected phase is instrumented. Acquisition and the other join call
the untouched helper. Allocation happens before the measured loop; numeric
trace storage is exported after the original worker cleanup. The bank reports
invocation count, observed rows, and `requested_cycles_all_traced` separately.
Zero observations are never complete. An aborted partial run can have complete
observations for its attempted phases without claiming the requested duration.
Original errors, raw records and cleanup results remain in the report.

Executing-copy, support, instrumenter and original-dependency hashes are
separate. Finalization labels the old cadence map as a **dependency** map,
rather than a claim that the original benchmark was executed. Both timing
admission and active-output eligibility remain false. Future callbacks are
qualified as after-completion observations, including already-done registration.
Missing or noncausal native wake values invalidate the trace; they do not change
or suppress the original control result.

## Local observer-cost measurement

`measure_overhead.py` defaults to PLAN. The explicit
`--measure-local-pipe --output /absolute/fresh/private/directory` option compiles
the pinned diagnostic C++ source locally and uses only its wait ABI with a
cancellation pipe. It never calls an exchange or opens a serial port, IMU or
model. This is a separate microbenchmark, not a robot diagnostic. It retains all
800 measured rows in four ABBA blocks per scenario, including outliers.

A local Mac measurement of the r2 instrumenter (`ab299e13…`) gave:

| Scenario | Baseline median | Observed median | Added median |
| --- | ---: | ---: | ---: |
| Synthetic owners already ready | 6.542 µs | 18.313 µs | 11.771 µs |
| Native cancellation-pipe wait, one poll | 206.605 µs | 214.166 µs | 7.562 µs |

The retained raw report SHA is
`1308c77170342ef7593ddb3501a8c004438edd183c81ad1b1032890f16775743`.
Preallocation and export are outside the timed section; binding/callbacks,
clocks and recording are inside. Native-case completions are synthetic on the
coordinator, not real bus workers. This does not reproduce Jetson scheduling,
GIL contention or a real boot check. Added observation cost can itself cause a
20 ms failure. No whole-loop speed or causal conclusion follows from it.

Run the portable file-only checks from the repository root:

```sh
PYTHONDONTWRITEBYTECODE=1 PYTHONPATH=runtime:runtime/tests python3 -B -m unittest \
  test_native_readiness_causal_trace test_native_readiness_causal_collector \
  test_native_readiness_causal_generation test_native_adaptive_readiness_wait -q
```

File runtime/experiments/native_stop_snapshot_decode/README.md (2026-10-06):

# Fixed STOP snapshot decode experiment

This file-only experiment reduces Python packet conversion work for canonical
STOP-proxy acquisition records. It is separate from the production transport,
collector, model and active controller. No runtime flag selects it, and it does
not open CAN/IMU, load a native library/model, change timestamps or approve output.

The original assembler creates one `Frame` for the request and one for the reply
of each of the twelve feedback records. The candidate matches canonical STOP
request bytes and the exact disabled, fault-free Type2 header directly, then uses
the same unsigned-16 decoding expressions. This removes those 24 `Frame`
allocations while retaining the full snapshot construction. Other allocations
remain. Type17 input is explicitly unsupported by the candidate.

`candidate.py` accepts only its four pinned Python source files. It extracts pure
codec/record/snapshot definitions with AST selection; it does not import the
production runtime. The candidate replaces only the packet conversion branch.
In the supported STOP domain, all remaining snapshot logic is the original code:
causal/full receipt checks, bus membership, duplicate/missing values, raw SI
conversion, IMU finite/causal checks, timing summaries and source flags. Malformed
STOP records retain the original error reason and check ordering. Outputs own
new list/dict descendants, leaving the original record bytes and IMU input intact.

The native exchange, completed-buffer seals, observer validation/model ranges,
post-inference freshness and final pre-send/native deadlines are still necessary.
This experiment does not replace them. The assembler's internal snapshot limit
is the original 100ms diagnostic limit; the real pipeline's stricter 20ms gates
are outside this experiment and remain unchanged. A passing experiment cannot
qualify a live controller or certify any physical measurement.

Default PLAN reads and verifies source hashes without compiling the isolated
engine or loading a model. Its default root is the included
`fixtures/frozen-source/`, containing the four exact original source files under
`runtime/singularitydog_hw/`. Later runtime changes do not replace this fixture
or its frozen hashes. These are source-only historical references; they are
never imported as a runtime package.

`--source-root` explicitly selects a separate repository or frozen kit root.
All four source hashes must still match; a newer repository source is rejected.
The hash checks and all timing/error conditions remain unchanged. No private
host paths or hardware identifiers are embedded in this experiment.

```sh
python3 -B runtime/experiments/native_stop_snapshot_decode/candidate.py
python3 -B runtime/experiments/native_stop_snapshot_decode/candidate.py \
  --source-root /absolute/path/to/frozen-kit
```

An optional bounded synthetic microbenchmark reports every wall/thread-CPU
sample in alternating baseline/candidate order. It measures only snapshot
assembly. Clock/list overhead is included, GC state/statistics are recorded but
unchanged, and actual native I/O, concurrent GIL scheduling, model inference and
final freshness gates are excluded. It provides no target latency improvement
claim. Saved actual records can later be passed to the isolated engine for an
independent CPU/file-only parity experiment; a saved-record CLI is not supplied.

```sh
python3 -B runtime/experiments/native_stop_snapshot_decode/candidate.py \
  --profile-synthetic --iterations 1000
PYTHONDONTWRITEBYTECODE=1 PYTHONPATH=runtime:runtime/tests \
  python3 -B -m unittest test_native_stop_snapshot_decode -v
```

The tests include 100 deterministic synthetic payload sets, exact whole-snapshot
and timestamp equality, baseline/candidate Frame counts, malformed/fault/mode/
wrong-bus/sentinel replies, incomplete receipts, duplicate/missing axes,
noncausal/stale times, nonfinite IMU, output mutation isolation, pinned-source
changes/symlinks/size rejection, explicit Type17 refusal and PLAN separation.
These are source/CPU tests, not device or ABI measurements.

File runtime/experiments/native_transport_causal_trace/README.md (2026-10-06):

# Separate diagnostic syscall trace proposal

This directory is a proposal and an isolated recorder regression. It is **not integrated** with any transport, collector, controller or existing ABI. Default `plan.py` only verifies the exact corrected diagnostic source and prints `PLAN_ONLY`. No execute/build option, native loader, device path or output permission exists.

```sh
python3 -B runtime/experiments/native_transport_causal_trace/plan.py
PYTHONDONTWRITEBYTECODE=1 PYTHONPATH=runtime:runtime/tests \
  python3 -B -m unittest test_native_transport_causal_trace_plan -v
```

`bounded_trace.hpp` is a fixed-capacity POD recorder with a synthetic/syscall-call wrapper. It invokes its noexcept callback once, preserves both the callback's incoming and outgoing errno across optional clock reads, and records a return value without retrying. A null recorder bypasses all clock work. Overflow and invalid/missing clocks are explicit; neither changes the original callback result. The supplied harness uses only fake callbacks/clocks, never a real syscall or transport. It is not an exported ABI or a ready live trace adapter.

## Proposed integration, still unimplemented

Build a separate, explicitly pinned STOP-only diagnostic library with an additional opt-in traced entry point or getter. Preserve the original `sd_exchange` signature and `SDRecord`/`SDStats` layouts; never overload their fields. Keep three preallocated trace slots per bus owner, one for acquisition, voltage and output, each with 256 event slots initially. Bind slots to the owner thread, bus, native begin timestamp, request sequence and original absolute deadline. No other thread may read a slot until its owner has finished. Overflow must prevent a complete-causality claim.

Bracket boot `pread` and `pselect`. Record requested absolute wake/relative timeout, result, saved errno, and serial/cancel readiness. Reuse existing read/write timestamps and preserve returned chunk sizes and all original bytes. Ready-bit capture, owner binding, separate-library selection and serialization are not implemented here. Capture errno immediately after each real syscall and restore it after tracing operations. Optional worker thread-CPU clocks are a separate, more intrusive mode.

Retain the failed coordinator cycle **after all owners settle**, even when a native exchange succeeds after the coordinator deadline. Keep a few bounded prior slots or per-call maxima for comparison. Failure-only persistence still incurs instrumentation during every measured call: compare traced and untraced runs separately and measure overhead. Do not allocate, print, write files, resend, alter timeout arithmetic, or substitute recorded source timestamps in the hot loop.

## What the evidence can establish

A long boot-read bracket locates elapsed time around that syscall; it does not alone distinguish kernel execution from preemption. A `pselect` timeout return later than the requested wait locates sleep/wakeup/return delay. A ready return cannot distinguish late USB data from delayed scheduling without kernel evidence. Several frames returned by one read prove host batching only. Wall time minus worker CPU time is not automatically GIL, USB or kernel waiting.

For the motivating failure, the final host `read` bracket was only a few microseconds, while the preceding gap was milliseconds. Existing records do not identify which part of that gap was boot checking, readiness waiting, OS scheduling or adapter delivery. The corrected relative-wait arithmetic is independently justified, but it has not established the cause of that specific delay. This proposal grants no active timing or physical-output qualification.

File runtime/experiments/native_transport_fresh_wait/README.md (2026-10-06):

# Fresh relative wait regression

The diagnostic transport source corrects one timing issue. In the original loop, `t` is captured before the boot-identity `pread`, then reused to compute a relative `pselect` timeout. Time spent in that check can extend the intended absolute wake. The corrected source reads the monotonic clock immediately before computing the timeout and rejects an already-expired original deadline.

`prepare_variant.py` accepts two exact reviewed source SHAs. Legacy input receives the single-block forward correction; already-corrected input is copied unchanged with an empty diff. The manifest names both source versions and the transformation. Unknown bytes are rejected. It keeps the input and output complete source plus a diff and manifest in a fresh directory. It never reverses the fix, compiles, loads a library, accesses hardware, or grants timing/actuation approval. Existing deployed binaries and frozen kits remain unchanged until a separate build and validation; callers are unchanged.

`fixtures/transport-before-fresh-wait.cpp` preserves the exact pre-fix source for deterministic comparisons. Tests verify that current production bytes equal the one-block forward transformation before compiling either source. It is a test fixture, not a runtime fallback.

```sh
python3 runtime/experiments/native_transport_fresh_wait/prepare_variant.py \
  --source runtime/experiments/native_transport/transport.cpp
```

Omit `--output` for PLAN. A fresh absolute `--output` directory writes the separate source artifact. A complete source file, rather than a hidden include dependency, lets a later separate build bind every compiled source byte. No build or live runner is supplied here.

The simulator intercepts every transport syscall before including either the legacy fixture or current production source. Tests do not open real device FDs. With a synthetic 2ms boot read, the same 5ms request gap becomes 7ms in the original and remains 5ms in the corrected source. A no-response timeout similarly reaches the original absolute deadline instead of 2ms afterward. These controlled examples demonstrate the defect; they do not establish the cause of any real robot overrun.

```sh
PYTHONDONTWRITEBYTECODE=1 PYTHONPATH=runtime:runtime/tests \
  python3 -B -m unittest test_native_transport_fresh_wait -v
```

Original cancellation, EINTR limit, absolute deadlines, no retry, allowed request kinds, matching and malformed-response behavior are preserved. One additional monotonic clock read per loop has a measurement cost. No reduction in USB/CAN response latency is promised.

## Remaining causal measurement

Current `SDRecord` timestamps identify host write and read brackets. Several frames can share the same `read_start_ns` and `received_ns` because one read returned a batch. `SDStats` records only aggregate wait/read counts. It does not record when an adapter received a CAN frame or when the kernel first made a serial FD readable.

A future isolated diagnostic can preallocate fixed event slots for `pread`, `pselect`, `read`, and `write`: entry/return wall and thread-CPU clocks, requested absolute wake/timeout, return value, saved errno, serial/cancel readiness bits, and returned byte count. Record incomplete/overflow explicitly and preserve the original errno. Never allocate, print, retry, or change deadlines inside those hooks. The event clocks add overhead and do not themselves distinguish kernel sleep from runnable scheduling delay; a bounded scheduler trace is needed for that distinction. USB arrival and CAN-wire timing need separately timestamped kernel/adapter evidence. This instrumentation is not implemented or enabled by this variant.

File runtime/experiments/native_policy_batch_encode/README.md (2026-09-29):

# File-only twelve-axis Type1 encoder candidate

`batch_encode.cpp` and `batch_encode_py.cpp` contain an isolated CPython C++
candidate. They neither open a device nor send a command. The active runner's
default remains its Python encoder. The opt-in loader pins both source hashes
and requires an independently reviewed binary SHA-256. Its startup canaries
compare exact Type1 bytes and rejection behavior before it returns an encoder.

Build on Jetson into a fresh temporary path using the cached Python 3.12
headers. The helper prints the binary SHA-256 and an explicit **unapproved**
status; it does not create or edit an output profile:

Run from the repository or source-kit root:

```sh
python3 runtime/experiments/native_policy_batch_encode/build_file_only.py \
  --compiler g++ \
  --include /home/jetson/singularitydog-tests/python-dev-headers-20260925/extracted/usr/include/python3.12 \
  --include /home/jetson/singularitydog-tests/python-dev-headers-20260925/extracted/usr/include \
  --output /tmp/sdbe_native.cpython-312-aarch64-linux-gnu.so
```

From the repository root, run the file-only loader and runtime wiring tests:

```sh
PYTHONPATH=runtime python3 -m unittest \
  runtime.tests.test_native_policy_batch_encode_loader \
  runtime.tests.test_policy_output_native_batch_integration
```

Live selection requires a separately approved V3 profile with the reviewed
`native_batch_encoder` path and SHA-256. The runner loads the extension before
enable and binds its displacement limits to the last pre-enable sample. The
fresh post-enable sample supplies the smooth starting target without resetting
the trial's displacement allowance. Any mismatch or encoding
error fails closed; it does not fall back during an active cycle. The existing
motion envelope, voltage/freshness gates, motor reply checks and STOP handling
remain in the runner. This is not a motor-output authorization.

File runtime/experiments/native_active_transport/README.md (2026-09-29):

# Bounded native active RS05 transport

This is a separate opt-in experiment. It does not change the diagnostic
`native_transport` library. It can send enable and position commands and must
only be called by the supervised active runner. The module never opens a device,
changes its baud rate, starts a worker, arms a motor, or loads a library on import.

Build locally for the target architecture, without installing dependencies:

```sh
python3 runtime/experiments/native_active_transport/build.py
PYTHONPATH=runtime:runtime/tests python3 -m unittest test_native_active_transport -v
```

The output is `libdog_active_transport.so` with a source/binary SHA-256 build
record. These generated files are ignored by Git. The build uses C++17 and the
standard library only. Tests use local socket pairs and PTYs; none open a robot,
serial device, network connection, or SSH session.

## API and ownership

`singularitydog_hw.native_active_transport.load_library(path)` verifies the
adjacent build record and monotonic-clock agreement before returning the library.

```python
session = ActiveSession(
    lib, caller_owned_nonblocking_fd,
    first_id=1,                 # exactly 1..6 or first_id=7 for 7..12
    cancel_fd=cancel_pipe_read_fd,
    boot_fd=caller_owned_boot_file_fd, boot_id=expected_boot_id,
    raw_lower_by_id=lower, raw_upper_by_id=upper,
    kp_max_by_id=kp_caps, kd_max_by_id=kd_caps,
    gap_ns=600_000, window=3,
)
records, stats = session.exchange(wires, timeout_ns=100_000_000)
```

Each limit mapping must contain exactly the bus's six integer IDs. Limits are
copied at construction. Both Python and C++ enforce raw position within
−12.57..12.57 rad, per-axis Kp at most 36, and Kd at most 1. These are software
experiment caps, **not manufacturer assurances of safe torque or safe support**.
The runner must supply tighter reviewed per-axis limits where appropriate.

Only one native session can own the same underlying FD (including duplicated
descriptors). A native mutex and Python lock reject overlapping operations.
The caller must also hold the project's cross-process port/common locks. The
caller retains the FD lifetime. `close()` releases the native handle, not the FD,
and does not send commands. The runner must complete STOP handling before close.

## Exact command and reply boundaries

| Request | Accepted payload | Reply |
|---|---|---|
| Type0 | all zero | exact source, host `FE`, Type0 UID |
| Type17 | indexes `7019`, `701B`, `701C`, `7028`, `7005`; reserved bytes zero | exact index/source/host `FD`, zero status/reserved; finite floats, uint32 watchdog or uint8 run-mode |
| Type3 | all zero | Type2, mode 0 or 2, fault 0 |
| Type1 | canonical zero FF and zero velocity; encoded position and gains inside configured per-axis limits | Type2, mode 2, fault 0 |
| Type4 ordinary STOP | all zero; never clear faults | ordinary Type2, mode 0; fault bits retained |
| Type4 version query, used before enable | exactly `00c4000000000000` | Type2 mode0/fault0 with `00c456` prefix, 4 raw version bytes, and separately retained byte7 |
| Type18, acknowledged exchange | index `7028`, reserved zero, exactly 4000 ticks | Type2 mode0/fault0 acknowledgement, followed by a separate Type17 readback and validation |

`send_only()` is retained for ABI compatibility but rejects calls. Watchdog writes
must consume their acknowledgement before the readback is sent.

`encode_motion(mid, q, kp, kd)` uses the same floor-to-u16 profile as the existing
RS05 trial codec. Zero FF and velocity encode as 32767. The C++ bound check uses
the **decoded quantized** position; a target exactly on a lower limit may round
below that limit and be rejected. There is no saturation, wrap repair or implicit
gain selection. Type1's middle 16 CAN-ID bits contain torque, not host `FD`.

All requested frames are validated before any write. Every OS write is exactly
one 17-byte AT frame. The minimum gap is measured from the preceding write's
completion, including preceding exchanges. At most three distinct request keys
are outstanding. Requests sharing an actuator and Type2 reply kind cannot be
mixed in one exchange. Cancellation, boot binding, FD binding and deadline are
checked before every write. The overall exchange budget is 1..250 ms.

`Record` matches the diagnostic layout. `Stats` preserves its existing fields and
adds `rejected_total`. Diagnostic `exchange_evidence(records, stats)` is compatible;
also retain `stats.rejected_total` to detect bounded raw-log truncation.
`decode_record()` reports raw values, mode and faults without declaring them a
valid calibrated robot state. Timing is host-side, not CAN-wire timing.

Version replies cannot acknowledge ordinary STOP/enable/Type1 commands, and
ordinary feedback cannot acknowledge a version query. The runner reads all
twelve raw fingerprints on the same bus owners before enabling, then compares
them to the tested watchdog evidence. A semantic version label does not replace
those bytes. This adds startup work only, not per-cycle communication. Emergency
STOP remains restricted to the all-zero payload.

## Fault and emergency STOP behavior

Partial writes, missing/late/unmatched/duplicate replies, unexpected RX, malformed
frames, partial tails, cancellation, FD/boot changes and invalid requests poison
the session. No active command is retried; C++ retains the poison even if the
Python flag is changed. A STOP that reports fault bits returns those bits and
also prevents later active commands. The supervisor must perform STOP handling
after any failure and preserve both the failing exchange and STOP evidence.

After cancellation, join the owner call before invoking:

```python
result = session.emergency_stop()  # 250 ms total for this six-axis bus
```

This method ignores cancellation, a changed boot ID, and poison **only to send
all-zero Type4 STOP**. It retains FD identity/nonblocking checks so that a reused
descriptor cannot receive actuator traffic. Its six independent time slices each
permit one individual STOP write; a missing reply from one motor does not prevent
the remaining attempts. No axis is retransmitted. STOP never clears faults.
The default 250 ms budget includes all six attempts; OS scheduling, disconnected
FDs, or an insufficient caller-selected budget may prevent an attempt, and the
returned `attempted_ids` makes that explicit.

The prior 150 ms default allocated about 25 ms to the first axis. In the first
supported output trial, matching front ID1/2 disabled replies missed those slices
and were retained as rejected bytes; confirmed replies on other axes took about
22–26 ms. The new default gives each axis about 41.7 ms. Replies are still accepted
only before their original, recorded axis deadline. The previous trial remains
STOP-unconfirmed; this change does not reinterpret its rejected replies.

This is a cleanup acknowledgement budget, not a change to the 20 ms active cycle
or the 200 ms device watchdog. When every reply is missing, the sixth STOP write
is attempted at about 208 ms rather than 125 ms; a single default call still budgets 250 ms per bus, with both bus owners
running independently. The repeated wrapper has a separate total budget below. OS
descheduling can delay execution beyond a configured deadline, so this is not a
hard real-time guarantee. No later motion is permitted while STOP collection is
running. An uncertain STOP still requires physical cutoff. Synthetic socket
regressions cover 28 ms replies, expired replies, and all-six missing replies;
the revised default has not yet been validated on the robot.

The JSON-ready result contains `complete`, `timeout_ns`, `deadline_monotonic_ns`,
`attempted_ids`, `confirmed_ids`,
`unconfirmed_ids`, `ambiguous_ids`, `fault_by_id`, decoded `replies`, and raw
`evidence`. Confirmation means a matching mode-zero reply was observed after
the write; it is not proof of physical cutoff. Pending motion/enable/STOP replies
from a failed earlier exchange make that motor's confirmation explicitly ambiguous.
A pending Type1 may respond in mode zero after watchdog/fault disable; it cannot
be distinguished from a new STOP acknowledgement.
An unanswered STOP from emergency cleanup is also remembered by the session.
If a caller attempts emergency STOP again on that session, a delayed reply to
the earlier attempt remains ambiguous even when it arrives after the new write.
The runtime calls `emergency_stop_repeated` on each bus owner. A successful first
round ends cleanup; otherwise at most three STOP-only rounds share one absolute
one-second budget. The first round retains a 250 ms cap; later rounds may use
500 ms or the remaining total budget. The collector uses a shared 1.25-second
wait including dispatch overhead. No motion is retried, fault evidence is
retained, and additional mode-zero replies never erase prior ambiguity.
There is no sequence number in Type2: very late duplicate replies cannot be
proven fresh by this transport. The runner must use freshness and state limits,
and an unconfirmed or ambiguous STOP requires the physical cutoff procedure.

Recovery preserves pre-write backlog and every skipped/malformed byte up to a
4096-byte evidence cap, plus total byte count and a truncation flag. This bounded
STOP-only parser may scan past malformed backlog; the active parser never
resynchronizes or discards bytes. Previously consumed failure bytes remain in
the original `ExchangeError.stats`. Emergency STOP leaves the session poisoned;
it cannot restart a trial.

This offline implementation and its socket/PTY tests are not a hardware trial,
watchdog validation, motor-scale confirmation, real-time guarantee, or approval
to deploy a policy. Mechanical support, cutoff readiness, identities, current
boot calibration, mode, watchdog readback/behavior, and fresh inputs belong to the
supervised runner's arming checks.

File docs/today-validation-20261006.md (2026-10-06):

# 10月6日（火）のToDo：校正を詰め、支持付き実出力へつなぐ

[今日の成果・修正・残件の○△×表](work-summary-20261006.md)に、無出力と実出力を分けて総括した。

**最新・r49：無出力の定常20ms以内を達成。** ID9調整後の12軸モデル範囲を照合し、C複製＋FK最適化を実通信へ接続。定常500周期を2回測り、最大19.856942／19.788521ms・20ms超過0、予定期限超過・周期スキップも0だった。初回20.066911／20.045173msは許容された初回として別記録。原通信・実入力・固定ソース・設定復元を独立確認した。次は新設定の実Type1出力を箱付きで2→10→20秒確認し、その後に荷重支持へ進む。[最新の○△×表と原測定](20ms-cause-investigation-20261006.md#r49c複製とfk最適化で無出力の定常20msを達成)。

**10月6日夜・r47まで（先行記録）：** 0.90ms送信間隔・20ms制御周期を維持し、C++待機と固定記録キャッシュを修正。関節目標のC++化＋FK再利用は保存入力と内部状態が一致し、モデル処理中央値1.680→1.586ms。読み込み修正63件に合格し、Jetsonでも実モデル・ライブラリのファイル検証を通過した。出力98値の旧C++変換はJetsonで遅くなり、不採用。r47の無出力5周期は後側34.808Vで代理STOP送信前に中止し、完了0周期。充電・交換後の新電源記録と角度を結び直し、5→501周期を測る作業が残っていた。新候補の連続20ms、現起動の正ゲイン・学習目標送信、荷重支持はこの時点では未確認。[原因・修正・実測比較](20ms-cause-investigation-20261006.md)。

**R18時点の先行記録：Jetson再起動後の無出力501周期は完了し、独立原本監査PASSでした。** 初回20.048744msは既存の初回21ms枠内、定常500周期は最大19.835106ms・処理超過0。匿名化した条件要約ではJetsonのみ再起動、40Vと姿勢の継続を記録し、40Vの電源区間は申告に基づいて引き継いだ。bootから電源・姿勢の継続を推定しない。現在姿勢の箱支持・4足接地・全12軸の約±3°の余裕・手離し・即時Offも直接確認済み。最新のSSH転送／PLAN確認が停止しており、再起動後のゼロゲイン診断と現条件の2秒・10秒・20秒実出力はまだ行っていない。

| R18で確認した範囲 | 結果 | 残る区別 |
|---|---|---|
| 無出力の初回1＋定常500周期 | ○・501周期、定常20ms超過0 | 初回は20msを超える。全開始間隔20msや実出力時間の保証ではない |
| 原通信・実float32入力・固定ソース | ○・全501周期を独立照合 | 取得STOP6,012件＋代理STOP6,012件、電圧1,002件、識別12件、24ソース・635ファイル。別の最終STOP確認はnull |
| 現在姿勢の現物確認 | ○・操作者の直接回答を保存 | 診断結果と合わせても、実出力profileの承認や試験完走には置き換えない |
| 保存ログの別形式への変換 | ○・Jetson上の実行receiptと原本との同値性を照合 | 新しい計測ではない。原本・時刻・通信bytesと16MiB読込み上限を維持 |
| 再起動後のzero・箱支持2秒→10秒→20秒 | 未実施 | 入口のソース準備まで。新しい実行承認・profile作成・出力成功は主張しない |

R18の定常開始間隔は499区間中257区間が20msを超え、最大20.007079ms。取得返信の最大間隔20.242445ms、IMU収録終了の最大間隔20.105161msで、21ms超過は0だった。電圧37.720890〜39.124454V、raw加速度norm10.626005〜10.711374m/s²、補正後9.778702〜9.861387m/s²、補正gyro norm最大0.006495048rad/sを記録。CPU・timer・GC・IMU等の復元も照合した。有効化・学習目標送信はなく、STOP代理診断を実Type1の時間保証や荷重支持の証明へ転用しない。

R18の保存recordsは17,633,838bytes。[保存ログ変換ツール](../tools/compact_diagnostic_evidence.py)をJetson上で実行した別ファイルは16,666,408bytesで、既存16MiB上限内に収まった。原本と全値・JSON型・辞書キー／配列順・float64ビット・通信bytes・時刻が一致し、原本SHAは不変。reportの変更はrecords SHAと変換元の明示だけで、元と派生のSHAを別に保存した。R17のMac上での変換記録は、その時点の履歴として下に残す。
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

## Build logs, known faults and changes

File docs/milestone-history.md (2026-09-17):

# 1・2・5・10・15・20・25・30・35・40回の進捗

2026年9月17日時点で、結果を確認した直近系列は**第37回（H01〜H04＋L00〜L32）まで**です。以下は指定された節目の一覧で、第40回は未実施です。回数は有限な診断・学習・評価をまとめた単位であり、成功回数、学習更新数、動画本数とは異なります。

| 回 / ID | 実施内容 | 得られた結果と残る課題 | 公開動画・根拠 |
|---|---|---|---|
| **1 / H01** | 92秒の荷重移動手順 | 31区間を完了し、4脚とも約20mmの挙上を保持。手順による診断で、学習歩行の成功ではない | 動画未掲載・[履歴JSON](../evidence/learning-history.json) |
| **2 / H02** | 周期化した参照を3条件で検証 | 各条件で全脚が15mm以上の足上げを3回完了。学習した歩行ではない | 動画未掲載・[履歴JSON](../evidence/learning-history.json) |
| **5 / L00** | 参照歩容＋残差学習250更新 | 4方向を各12秒完走、前進10.37cm/s。後左脚の足上げ不足・滑り・偏向が残る | [4方向MP4](media/l00-four-directions.mp4)・[記録](video-history.md) |
| **10 / L05** | 回転慣性を修正して500更新 | 前進16.54cm/s（変位÷12秒）。20cm/s未達、後左脚不足・後進の滑り・右の偏向が残る | [4方向MP4](media/l05-four-directions.mp4)・[記録](video-history.md) |
| **15 / L10** | 左右旋回を追加し500更新 | 前進32.16cm/s。前進・後進・右の3/6方向が全基準達成、左速度と旋回の位置保持は未達 | [6方向MP4](media/l10-six-directions.mp4)・[評価](l10-evaluation.md) |
| **20 / L15** | 位置・方位・起立報酬を加え500更新 | 24秒・2周期完走、伏せ各2秒。第2起立保持1.9375秒、最大XY69.344mm・方位21.458°で総合未達 | [伏せMP4](media/l15-model499-stationary-prone.mp4)・[評価](l15-evaluation.md) |
| **25 / L20** | 4専門方策、実行500更新 | 保存系列は488更新分、12更新は未保存。9動作の全登録基準は2/9合格 | [9動作MP4](media/l20-nine-motions.mp4)・[評価](l20-evaluation.md) |
| **30 / L25** | 独立A/B/C各500、計1,500主更新 | 各7/9合格。伏せB/Cは保持・復帰各2秒×2、高い挨拶も維持したが、位置・方位基準が残る | [A](media/l25-a-nine-motions.mp4)・[B](media/l25-b-nine-motions.mp4)・[C](media/l25-c-nine-motions.mp4) MP4・[評価](l25-evaluation.md) |
| **35 / L30** | 伏せ5・挨拶4試行、計277主更新 | 新規合格0。最新伏せはXY100.320mm、挨拶は61.583mmで未達。9動作全体の再評価はしていない | 新動画なし・[評価](l30-evaluation.md)・[数値比較図](media/l30-checkpoint-comparison.png) |
| **40 / —** | 未実施 | 第37回までを確認。第40回の結果・動画・成功数は未計上 | — |

第30回の比較動画は14秒の表示用抜粋です。合否は各動作の全評価時間（12／24／36／32秒）に基づき、表示終了後の静止画を保持成功時間へ含めません。動画のない回へ他の回の映像を割り当てていません。

第10回の元速度平均は16.57cm/s、上表は変位÷12秒の16.54cm/sです。物理モデル、指令、対象動作、合格基準が途中で変わるため、全回の値を同じ試験の改善率として比較できません。第25回と第30回の9動作は別専門方策の個別評価で、単一方策が連続切替できた結果ではありません。

## 第35回以降の確定結果

| 回 / ID | 学習と診断 | 結果 |
|---|---|---|
| **36 / L31** | 最終r8は挨拶500主更新・起動確認2更新、256,000遷移 | 最大XY61.528mm、50mm基準未達。36秒・計4往復・高挙上8秒・復帰各2秒を維持。新規合格0。[評価](l31-evaluation.md) |
| **37 / L32** | A/B各500、計1,000主更新・起動確認計4更新。D/Eは更新0の固定診断 | A/B最終XY61.633／60.509mmで未達。BのPPO改善は0.003292mm。Eは29.8秒・XY157.021mmで停止。新規合格0。[評価](l32-evaluation.md) |

第36・37回は数値要約を公開し、動画は未公開・未目視です。従来の移動6方向とお座りの7動作を保持したことと、この2回で9動作を再検証したことを区別します。学習を完了しても、元の合格基準を満たさない候補は採用しません。

元の対応関係は[履歴JSON](../evidence/learning-history.json)、第5〜30回の選択値は[改善一覧JSON](../evidence/improvement-loops.json)、第35回は[評価JSON](../evidence/l30-evaluation.json)、最新2回は[第36回JSON](../evidence/trial36-results-summary.json)・[第37回JSON](../evidence/trial37-results-summary.json)に基づきます。

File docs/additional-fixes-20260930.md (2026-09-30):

# 9月30日：追加監査で修正した課題

実機再開前に、結果判定・設定準備・送信角度の量子化・キット照合を追加監査した。今回の変更はMac上のソフトウェア修正で、Jetsonへの配布やモーター駆動は行っていない。

## 修正した問題

| 状態 | 見つかった問題 | 対策と確認方法 |
|:---:|---|---|
| ○ | 1軸の古いSTOPを、他軸の新しいSTOPで補って終了確認が通る | 全12軸それぞれについて、最終制御周期・最後のType1／有効化返信の後のSTOP要求と停止返信を照合。STOP後の追加出力も拒否 |
| ○ | Type4という種別だけ合えば、正規STOPと異なるバイト列を採用する | 実際の要求全バイトを正規STOPと比較 |
| ○ | ログの申告速度がゼロなら、目標角が急変しても合格する | 保存された名目目標の時間差分を、実送信バイトとの一致確認に加えて照合。CAN量子化の段差は名目目標速度と混同しない |
| ○ | `normal_ramp_completed=true`だけで正ゲインの末尾を正常終了とする | 最後の実送信がゼロゲイン・停止完了フェーズであることを確認 |
| ○ | 古いソースの無出力診断が、現ソースの準備結果でも有効に見える | ソースSHA、起動、電源世代、角度記録の結合状態を別記。欠落・不一致は`NOT_ELIGIBLE`。過去の時間値は参照用として残す |
| ○ | 設定準備の途中でモデルファイルが変わる | 公開直前にもモデルbundleを再照合。検査・JSON生成を出力ディレクトリー作成前に終える |
| ○ | 滑らかな浮動小数の経路だけで、整数変換後の送信角度を評価する | Type1の量子化後も位置範囲・変位・静止PD推定を検査。有効化前とゼロゲイン初期化後の始点にも適用 |
| ○ | 同じファイルを別表記で重複計上できるマニフェスト | 空・重複一覧、`a//b`や`a/./b`等の非正規名、型不正、重複JSONキーを拒否。ジョブ起動前の照合にも反映 |

最初の5件は、修正前の評価器で不正な合成ログが合格することを再現した。実機でSTOPできなかった原因を新たに特定したという意味ではなく、保存ログからの合否判定の修正である。r64の原ログ143周期は新しい名目速度・最終ゼロゲイン条件にも適合したが、新ソースで再実験した結果ではない。

## 量子化と20ms周期

Type1位置指令の1段は`25.14 / 65535 rad`、約0.02198°。滑らかな微小経路でも、符号・原点・360°の枝を保って整数へ変換すると送信目標に段差ができる。速度・加速度の数値は次の3種類を区別する。

- 浮動小数の経路に適用する名目速度・加速度の上限。
- 量子化された送信参照値の差分。新しい`preload_wire_reference_audit`へ別記し、実際の関節速度・加速度の測定値とはしない。
- 実機から返る速度・トルク・位置。従来の監視を継続し、今回の修正で上限を緩めない。

詳細な251点×12軸の量子化監査は、有効化前の準備中に行う。ランタイムへ保存する監査の基準は元の確認済み姿勢（`reviewed_capture`）であり、その後の実送信全バイトを監査したという表示にはしない。新しい始点での許容範囲は、各軸の最小・最大値の24点で全経路を確認できる。符号を含む変換の単調性と、全251点の列挙結果の一致をテストした。

この始点検査はMac上の参考計測で約2.5msから中央値約0.067msへ短縮。実機の20ms周期達成を示す計測ではない。詳細監査は約7.7msかかるため制御周期内には追加していない。Pythonと実際にビルドしたC++の位置エンコーダーについて、境界値と全経路の位置コードを照合した。

## 次回のToDo

| 状態 | 作業 | 次の確認 |
|:---:|---|---|
| ○ | 今回のオフライン修正 | ソフト検査と履歴ソースの照合を保存 |
| × | 新キットをJetsonへ配置 | ビルド・ソース／モデル一致、現起動・電源・角度・電圧・通信断保護、無出力計測 |
| × | 箱を残した5秒の伸展・復帰 | 指令と実測の追従、復帰、全12軸STOP、元動画と現物観察 |
| × | 荷重用の学習モデル設定 | 現姿勢からの目標範囲・開始遷移・必要ゲインを支持下で確認 |
| × | 部分荷重・四足自立・低速歩行 | 全重量を受けられる補助を保ち、荷重・滑り・沈み・停止を段階ごとに確認 |

手順と作業時間は[歩行までのToDo・スケジュール](walking-plan-20260930.md)へ集約する。今回の修正で実機の未実施項目を○に変えない。CAN／USB欠落の物理的原因と長時間再現性、全重量支持に必要な設定、動加速度中のIMU精度は引き続き実測が必要。

過去の成功を比較できるよう、r64のソースSHAは変更せず、今回変更した旧評価器も別保存した。178ファイルのうち5ファイルが履歴専用コピー、173ファイルは一致する現行ソースを参照する。

## 修正後の検証

- 関連ランタイム43モジュール：789件中786件合格。保存モデル比較データ未指定の3件はskipで、モデル同等性の新しい実証には数えない。
- 準備・マニフェスト・経路・検証レポート・履歴照合ツール：78件合格。
- 伸展・復帰の専用54件：全件合格。[ソースとテストを固定した結果](../evidence/supported-preload-software-20260930-r2.json)と[実行ログ](../evidence/supported-preload-software-20260930-r2.json.log)を保存。PythonだけでなくC++エンコーダーをビルドして照合した。
- r64履歴ソース178件のSHA-256一致を確認。

旧[47件のレポート](../evidence/supported-preload-software-20260930.json)はコミット2acbd34の履歴として保持し、新コードの合格根拠へ流用しない。

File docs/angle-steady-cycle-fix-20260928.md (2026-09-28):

# 9月28日夜：電源再投入の角度補正と初回・定常周期の分離

40VのOff→On前後を同一起動で読み取り、12軸のUID一致と角度差最大0.008524°を確認した。操作者は「40V Off→On完了・姿勢は同じ」と確認している。**今回の操作では360°ずれは再発しなかった**ため、ずれが発生した実機での補正成功とは区別する。生記録と前後比較はMacへ保存した。

その後の[5回連続の再投入比較](power-cycle-repeat-20260928.md)でも360°ずれは出なかった。全12軸の`zero_sta=0`を読み取り、起動時の0〜2π範囲への再初期化が過去の一回転差と整合すると確認した。ただし3回目には最大3.306°の非周回変化が残り、原因の確定と原点・正方向の現物照合は完了していない。

## 角度補正の修正

読み取りと実出力の逆変換に、同じ通電区間の固定補正を使う。

```
q_model = sign × raw + offset_current
offset_current = offset_calibration − sign × turns × 2π
raw_target = (q_target − offset_current) / sign
```

`turns`は、確認済みの機械可動域と角度誤差を含めて一意に選べる場合だけ決定する。従来の有限候補列挙を共通の数式へ置き換え、実出力前の判定にも機械可動域・誤差幅を使うよう修正した。読み値を単純に`%360`へ置き換えると、現在のQDD座標と送信目標の座標が食い違うため、この固定補正を両方向へ適用する。

通電区間が不明、候補が複数、誤差幅が機械限界を超える場合は有効化前に中断する。同じ通電区間で読値が急変しても自動で再補正しない。通電区間ラベルだけで電源操作を自動検出できるわけではなく、原点・正方向・機械範囲の現物確認も別に必要である。

過去のID3の+361.307°とID9の負の一回転を再現するテストで、補正後の現在角とType1送信値の逆変換が一致した。関連240テストと出力スモーク9テストを確認し、Jetsonでも角度・実出力ランタイム・待機処理の69テストを確認した。件数には重複があり合算しない。実機へType1指令を送った検証ではない。

## 初回1周期の扱い

操作者の「開始の1回は20msを超過してもいい」に合わせ、初回1周期と定常500周期を分けて判定する選択肢を追加した。全501周期の取得・推論・26要求の返信・後処理と生時刻は保存し、初回の超過も集計から消さない。途中の超過は引き続き失敗として数える。

次の三つを別々に報告する。

- 実開始から返信後処理終了までの処理時間が20ms以内か。
- 固定20msスケジュールの終了期限に間に合い、周期を飛ばしていないか。
- 定常周期の実開始間隔が厳密に20ms以内か。微小なスケジューラ遅延も記録する。

名目20msで起動する処理では、実開始間隔に起動遅延の差が乗る。中央値が20ms、あるいは処理時間だけが20ms未満でも、厳密な開始間隔の合格とはしない。許容ジッターやモデルの20ms刻みは変更していない。

選択式のC++期限待機も追加した。取消FDを監視しながら期限直前まで待機し、最後の200/500µsだけ時計を確認する。シリアル機器を開かず、待機後の実時刻を記録する。既存ライブラリは、この機能を選ばない場合に引き続き使用できる。既定設定には採用していない。

## 先行実機結果：R14、22:13開始

前後CAN・IMUを並列取得し、実推論とSTOP代理を行った。0.8ms間隔・未返信上限3・26要求、主スレッドCPU4、ワーカーCPU0–3、C++期限待機500µs、初回1＋定常500周期の結果である。

| 指標 | 結果 |
|---|---:|
| 初回処理時間（許容対象） | 20.007973ms |
| 定常500周期の全工程中央値 | 18.831873ms |
| 定常の全工程p99 / 最大 | 19.185445 / 20.734286ms |
| 定常の全工程20ms超過 | 2 / 500周期 |
| 定常のスケジュール終了期限超過 | 2 / 500周期 |
| 定常の周期飛び | 0 |
| 定常の実開始間隔p99 / 最大 | 20.003296 / 20.782609ms |
| 厳密な20msを超えた定常開始間隔 | 248 / 499間隔 |

超過した全体の第164・471周期では、モデル本体が4.119580 / 4.145372msへ伸び、全工程は20.509828 / 20.734286msだった。主スレッドCPU時間も増えており、期限待機だけで解消する現象ではない。初回除外後も**定常20msは未達**。CPU配置・周波数範囲とIMU設定は復元を確認した。モーター有効化・学習目標送信は行っていない。

保存入力を用いた先行のATen dispatch統合候補はJetsonでも500周期の目標・観測・内部状態が完全一致し、26拒否ケースと240合成入力の確認を通過した。中央値は2.224958→2.124489msで約0.10ms短縮したが、これだけで実機の超過を解消したとは言えない。この数値は後述のscalar実装の短縮量ではない。

## 22:33時点の最新実機結果：scalar単独と巡回電圧の重畳

同じ起動・同じ物理通電区間で、初回1周期を保持したまま定常500周期を3回測った。各周期は前後CANで全12軸の複合feedback、巡回電圧各バス1件、全12軸STOP代理の**計26要求**を完了した。3回とも生記録は501行・計13,026要求で、Type1・モーター有効化・学習目標送信は0だった。0.8ms間隔、未返信上限3、主スレッドCPU4とワーカーCPU0–3、500µsの選択式期限待機、trace記録を使い、CPU・GC・IMU設定の復元を確認した。scalarモデルは診断用ローダーで利用し、実出力ランタイムには採用していない。

| 指標 | R16 scalar単独 22:30 | R15 scalar＋電圧重畳 22:32 | 同条件再試行 22:33 |
|---|---:|---:|---:|
| 初回処理時間（記録して別判定） | 19.388177ms | 19.676083ms | 19.051560ms |
| 定常500周期の全工程中央値 / 最大 | 18.292255 / 20.082833ms | 18.480045 / 19.022997ms | 18.495498 / 20.227358ms |
| 定常の全工程20ms超過 | 1 / 500 | 0 / 500 | 4 / 500 |
| 定常の固定スケジュール終了期限超過 | 1 / 500 | 0 / 500 | 5 / 500 |
| 最古入力開始→最後のSTOP返信、全501周期の最大 | 18.729906ms | 18.897553ms | 19.836808ms |
| 実開始→最後のSTOP返信、全501周期の最大 | 19.134054ms | 19.424456ms | 20.019344ms |
| 定常開始間隔の20ms超過 / 最大 | 247 / 499、20.132211ms | 254 / 499、20.010369ms | 237 / 499、20.269447ms |
| 周期飛び | 0 | 0 | 0 |

全工程は実開始からSTOP返信後のtraceコピーと周期内で行う参照解除までで、タイミング行の組立前に終了時刻を取る。電圧重畳では推論入力の`acquisition_ms`と`input_latest_reply_ns`は6件ずつのfeedbackとIMUまでを表し、電圧返信・検証の時刻は別に保存する。電圧は推論中に読み、両バスの返信と35–42V範囲を確認してからSTOP代理を送る。全工程と固定スケジュールの終了判定には電圧待ち・検証を含む。

22:33の再試行では全工程の第82–84・338周期が20msを超え、推論は順に5.031658・5.063761・5.039404・4.514963msだった。第85周期も、前周期群からの開始遅れにより固定スケジュール終了期限を超えた。最古入力から最後のSTOP返信は全501周期で20ms未満だが、**実開始から最後のSTOP返信は再試行で1周期だけ20msを超えた**。22:32の単回0/500を継続達成とは扱わず、厳密な実開始間隔も3試行とも未達である。

別の[Jetson保存入力scalar実験](../runtime/experiments/native_policy_overnight/model_call_fastpath/README.md)では、500回の順序付き再帰入力で目標・観測・全名前付き状態が完全一致し、26拒否ケースと240合成入力でも一致した。隔離したモデル呼出しの中央値は2.270622→1.735172ms、短縮0.535450msだった。これは先行の約0.10msのATen dispatch候補と別の実装・比較で、保存入力の速度を実機全工程の達成に置き換えない。

## 22:44時点の追加実機結果：電圧検証ワーカー

前節と同じscalarモデル・26要求・初回1＋定常500周期の無駆動条件で、IMU読取りを終えたワーカーへ電圧検証を選択式で渡した。前後バスの巡回電圧返信をまとめ、feedback・IMUとの一致と35–42Vを検証する。主スレッドは推論後にその結果を待ち、**実際の推論後時刻で全14件のCAN入力とIMUの鮮度を再確認してから**STOP代理を送る。両試行とも全501周期・計13,026要求の返信と検証時刻を保存し、Type1・モーター有効化・学習目標送信は0。CPU配置・GC・IMU設定も復元した。Macの関連136テストとJetsonの電圧重畳13テストを確認した（件数は他のテストと重複し、合算しない）。

| 指標 | 22:43の初回試行 | 22:44の再試行 |
|---|---:|---:|
| 初回処理時間（記録して別判定） | 19.496740ms | 20.604890ms |
| 定常500周期の全工程中央値 / 最大 | 18.677438 / 19.840034ms | 18.655258 / 19.455481ms |
| 定常の全工程20ms超過 | 0 / 500 | 0 / 500 |
| 定常の固定スケジュール終了期限超過 | 1 / 500 | 0 / 500 |
| 最古入力開始→最後のSTOP返信、全501周期の最大 | 19.452054ms | 19.821635ms |
| 実開始→最後のSTOP返信、全501周期の最大 | 19.637611ms | 20.340412ms（初回のみ） |
| 定常開始間隔の20ms超過 / 最大 | 239 / 499、21.552385ms | 252 / 499、20.011825ms |
| 周期飛び | 0 | 0 |

最初の試行は定常第349周期の開始が予定より1.566252ms遅れ、処理自体は18.790986msでも固定スケジュールの終了期限を0.357238ms超えた。再試行は初回が20msを超えたが、操作者の例外対象として生時刻と件数に残した。再試行の定常500周期は処理時間と固定スケジュール終了期限の両方で0件だった。ただし**厳密な実開始間隔は両試行とも未達**であり、実出力50Hzの証明ではない。

`validation_overlap_enabled`は選択した方式を示し、全周期で推論と検証が時間的に重なった意味ではない。保存時刻では検証完了が推論終了より早かったのは初回試行51／501周期、再試行77／501周期、計128／1000定常周期だった。全周期で検証・最終鮮度確認はSTOPの実送信開始より前に完了した。定常全工程の中央値18.677438／18.655258msはR16 scalar単独の18.292255msより長い。従来の電圧重畳2試行、scalar単独試行、R14の失敗例も上に残し、今回の0／500を厳密な連続20ms達成へ読み替えない。

原本のSHA、前後角度比較、初回・定常の集計は[機械可読サマリー](../evidence/angle-steady-cycle-fix-20260928.json)に保存した。元の通信ログは非公開のMac保存先とJetsonに保持する。

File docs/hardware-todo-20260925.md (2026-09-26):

# 次回のToDo — 2026-09-25以降

現在の優先順位・解消方法・完了条件は、[9月25日の対策計画](hardware-remediation-plan-20260925.md)に整理しました。以下は実施前のToDoと追記を含む履歴です。

**r7追記：** 起動IDの確認処理を共通化し、個別STOPの前6台全返信まで38.281ms→30.223msを観測しました（各1回）。全12台の通信・停止返信も再確認済みです。[比較結果](hardware-stop-guard-20260925.md)。[RS05 0.5.0.13の正規BINと更新準備](rs05-firmware-0.5.0.13-update-20260925.md)も整えました。FW書込みは未実施で、現在は全台0.5.0.9です。

2026-09-24の相談内容を記録。以下の実装・実機比較は明日以降に行う。自動実行の予約はしていない。

**2026-09-25追記：本日は[Active Reportingを先に検証する試験計画](hardware-test-plan-20260925.md)を優先します。** 各QDDの自動報告で毎周期の読出し要求を省けるか、1台→前6台／後6台→12台→IMU・推論・STOP代理送信の順に確認します。以下は残りの改善候補として保持し、送信側のまとめ書込みは新しい統合測定で必要性を判断します。計画作成時点では未実装・未計測です。

**最新の実施結果：** ID1は60秒完走。ID3を固定した比較は単独で成功、3台で解除失敗、6台で開始応答が欠けて中断しました。全12台のFWは0.5.0.9を再確認。報告解除後、全12台の識別・STOP・静穏・閉鎖を確認済みです。自動報告の12台運用は保留し、FW／CAN線上の切り分けと並行して、既存Type2方式の送信短縮へ進みます。[測定結果と次の手順](hardware-active-reporting-20260925.md)

入力組立ての改善実装は完了し、Jetson上で保存データを再生した「準備＋組立て」の中央値は旧1.546ms→新1.324〜1.330ms（約14%短縮）でした。実入力の取得・推論・送信へはまだ接続していません。

**送信側の検証も実施済み：** 前6台のSTOPを1／2フレームずつ書く条件は完走しましたが、3フレームはID3返信欠落で中断。その後の前脚側通信停止はUSB抜き差し・40V Off／Onで復旧し、全12台の識別・STOP・静穏を再確認しました。6フレーム一括・前後同時への拡大は未実施です。[まとめ送信の結果](hardware-stop-batch-20260925.md)

次の優先作業は、表2の処理内訳と従来の1フレーム方式の改善、表6の残るCPU処理の短縮です。表3〜4は限定試験まで完了しましたが、信頼性の条件は未達です。連結フレーム数の拡大より欠測原因の切り分けを優先し、その後に表7の全工程を再計測します。

## 引き継ぐ測定結果

- 並列取得は中央値14.483ms。前CAN・後CAN・IMUは既に並列で、3回ともCANの完了が最後だった。
- 取得時の送信間隔は設定0.5msに対し、30区間の実測中央値1.705ms。
- 推論後のホスト送信幅は中央値9.467ms。送信間隔30区間の実測中央値は1.137ms。
- 9.467msだった回の遅い側のバスは、送信・直前確認の計測区間2.264ms＋送信間7.204ms。後者は受信・検査・記録・実行待ちを含み、全量を削減できるとは未確認。
- 最古入力の取得開始→最終ホスト送信は中央値37.780ms、最後の返信まで40.416ms。20ms未達。
- これは停止命令による代理測定。推論目標の実送信、連続50Hz、学習モデルでの歩行は未実施。

数値は9月24日の統合試験3回とその保存ログの再解析に基づく。単発測定から最悪時間を保証せず、別々の中央値を足して全工程の時間としない。

## 実施順

| 順番 | ToDo | 完了条件 |
|---|---|---|
| 1 | 前脚ID1〜6・後脚ID7〜12の6台分を、周期番号・期限付きの変更不能な指令バッファとして事前生成・検査する | ID対応、順序、フレーム内容、期限切れ・範囲外・重複IDの扱いをオフラインで確認。各ポートの所有者を1つに保つ |
| 2 | 取得・送信に共通する処理を計測し軽量化する | 送信可能時刻から実書込みまでを、受信処理・共有ロック・確認処理・ログ複製・実行待ちに分ける。詳細記録の整形を周期外へ移し、欠測・故障・期限の判定は維持 |
| 3 | USB2CANへのまとめ書込みを別の比較モードとして準備する | 連結フレームの処理可否、キュー容量、部分書込み、遅延返信、停止までの挙動を検証できる構成を作る |
| 4 | 同じ条件で1台ずつ／2台ずつ／3台ずつ／6台一括を比較する | 駆動を伴わない限定試験から開始。全12台の要求・返信対応、欠落、残留、ホスト書込みと返信までの時間を比較。欠落を再送で隠さない |
| 5 | CAN短縮後にIMUの待ちを確認する | IMU読取り自体は約1.4〜2.5msだが、最古入力の開始から完了までは約8.2〜10.4ms。開始遅れ・更新待ちを分け、元の取得時刻と鮮度を保持 |
| 6 | 入力組立・推論の残る重複処理を削減する | 再デコード・コピー・証跡生成を整理し、同じ入力に対する出力・内部状態・異常時の動作を照合。CPU処理が支配的な箇所をC++化候補とする |
| 7 | 並列取得→単一推論→前後送信を接続して再計測する | 同じ単調時計で最古入力から最終ホスト書込み／最後の返信までを記録。最大・分位点・欠測・期限超過数・入力年齢も集計する |
| 8 | 実出力と連続周期の検証へ進む | 校正・Type2速度換算・IMU・指令範囲・全軸停止の残条件を満たしてから、支持下の有限試験へ。代理測定の合格と実制御の合格を区別する |

## 6台一括方式で確認する点

- 前後2バスの並列化と、各バス内のまとめ書込みは別。6台分のリストは既に一部で使われているが、現在の物理書込み境界は1フレームずつを検証している。
- 現行の統合試験は未応答上限4・送信終了後0.5ms間隔。6台一括は両条件も変えるため、単なる配列化による効果と混同しない。必要な箇所だけ検証済みバッチに対応させ、任意のバイト列を許可しない。
- 6フレームは17×6＝102バイト。UART 921600bps・8N1で約1.11msは線上の計算値であり、USB・変換基板・CAN・返信待ちを含む実測ではない。
- 一度にキューへ渡した後はフレーム間で中断判断できない。部分書込み時に何台まで送れたか、古い指令が残る時間、停止経路を比較対象に含める。
- 一括書込みの開始・終了時刻から個々のCANフレームの実送出時刻を作らない。入力時刻・年齢を付け替えて20ms達成としない。

最初の取得時間の実験目標は10ms前後。達成予測ではなく、全工程20msには送信・入力組立・推論の改善も必要。

## 参照

- [9月24日までの実機開発まとめ](hardware-summary-20260924.md)
- [20ms化の実装・測定履歴](control-20ms-strategy-20260924.md)
- [公開集計](../evidence/hardware-results-20260924.json)

このToDoの追加時点では、通信実装の変更・Jetsonへの転送・実機送信は行っていない。

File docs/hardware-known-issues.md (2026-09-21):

# 実機の既知の問題・交換判断

**2026-09-21最終状態**：右前脚の限定駆動と停止は確認済み。下記には中止時点の記録も残す。最新の到達点・未解決課題は[実機集計](hardware-results-20260921.md)を参照。

## HW-ID11-POS-001：左後脚中央 RS05 の位置値飛び

記録日：2026-09-20。更新：2026-09-21。状態：**交換済み・別個体の認識と手動5姿勢の再記録完了、制御用校正は未検証**。

以下には交換前後の当時の記録を残す。11:19の左後脚再記録を含む最新状態は
[実機準備状況](hardware-readiness-20260921.md)を参照。

2026-09-20のユーザー方針は「ID 11の値とびは、記録して、問題発生時に交換」。2026-09-21の手動校正後に交換を決定し、続いて「11交換しました」と報告された。読み取りでID11だけ個体UIDが変わったことを確認した。故障原因確定・校正完了とは扱わない。

### 確認できた事実

- 対象はユーザー申告の CAN ID 11、左後脚の中央関節、RobStride RS05。
- HW-036 では位置値が約332.326°と378.789°の間で切り替わった。HW-046にも約46°の一時的な変化がある。
- 左後脚のL字姿勢を記録したHW-046/047では、位置中央値に約43.271°の差が出た。ユーザーは「ほぼ同じL字を保持していた」と回答。
- 生の受信フレームにも値の変化があり、送信元ID・位置レジスタ・データ型の照合と再解読は一致。変換処理の取り違えやタイムアウトは確認されていない。原因とモーター故障は未確定。
- 続くHW-048は12.2秒・各関節60点の読み取り。ID11の位置幅は0.0227°で、大きな飛びは再現しなかった。異常解消を証明するものではない。

[メーカー仕様](https://github.com/RobStride/Product_Information/blob/main/README.md)の減速比7.75:1から、入力軸1回転に相当する出力角は360/7.75 ≈ 46.4516°。過去の飛びに近い数値だが、これは原因調査の手掛かりにとどめる。46.45°の自動加減算や外れ値除去で校正値へ取り込まない。

### 交換と再確認の扱い

1. ID11を既知問題として残し、値飛び・姿勢ずれ・異常な動作が出た時点のログと状況を保存する。
2. 制御中に位置値の整合が崩れた場合は、その値を追って動かさず試験を停止して現物を確認する。これは今後の運用要件であり、専用の値飛び検出機能を実装済みという意味ではない。
3. ユーザーがID11を交換済み。旧個体は問題履歴とともに区別して保管する。交換後の確認は読み取りだけで行っている。
4. 交換後はIDと部位の対応、回転方向、原点、可動範囲を再確認し、旧個体の補正値を流用しない。

### 2026-09-21 交換前の手動校正の結果

- 最終セッションは10:28〜10:37、20姿勢に対して再試行を含む49記録。14姿勢が観測品質の条件を満たし、全体は`OBSERVATIONS_PARTIAL`。
- 右後脚は5姿勢が揃い、ID7/8/9の原点・方向候補が作成された。候補は未検証で実機制御へ未適用。
- 右前・左前・左後は上脚の向き確認とL字へ戻した記録が未成立。ID11以外にも取り直す姿勢が残る。手合わせのずれとセンサー異常は、この集計だけでは同一視しない。
- ID11の旧個体情報と全記録は非公開領域へ保管。新個体のUIDを照合し、旧個体の履歴と区別する。
- 最終セッションのID11には、1キャプチャ5サンプル中の位置幅が46.488°、46.466°となる記録が2件ある。これは報告角度の変化で、実際の脚の動きを直接測った値ではない。既知問題の再発を疑う記録として残し、自動的な角度補正は行わない。
- 手動ツールr1は既知問題としてID11の候補生成を保留する実装。交換後は旧個体とのUID相違と新個体の安定性を確認した上で、この保留の扱いを更新する。番号だけで問題解消としない。

### 交換後の読み取り（2026-09-21）

- 全12個体を識別。ID11のみ交換前と異なるUID、ほか11個体は一致。
- 約12.25秒で各60サンプル。ID11位置幅0.02268°、隣接サンプル最大差0.01983°。この窓では約46°の飛びは観測されなかった。
- ID11電流0A、電圧36.809〜36.844V。速度の最大読み値0.12056rad/sは従来の注意しきい値を超えるため、位置が安定していた事実と分けて記録する。
- 全2,892件の要求は識別・読み取りのみ。通信エラー・破棄bytesなし。駆動・原点設定・設定変更なし。
- 交換前後の読み取りファイルとハッシュを非公開の交換記録に残す。確認した新UIDのみ、新しい左後脚セッションから原点・符号候補を作る。旧個体の候補は継承しない。
- 静止時の短時間観測であり、可動範囲全体・負荷時・電源再投入後の問題解消を証明するものではない。

写真・動画・個体UID・生ログは非公開の記録へ保存している。

## HW-CAN-BURST-001：3軸連続送信時の応答欠落

2026-09-21、右前脚3軸の開始前停止確認でID3の返答が2回欠け、有効化前に中止した。
識別要求の比較では、間隔なしでID1の応答も欠けた。特定モーターの故障とは断定していない。
書き込み完了から最低5msの間隔を導入し、関連27テストをMacとJetsonで通過。
別途、5ms間隔の識別60要求は全応答を取得し、その後の停止試験では3軸の停止状態0・故障0を確認した。
修正後の準備試験も送受信45フレームが一致した。その後14:52〜14:55の右前脚限定駆動3回では各411送受信を照合できたが、長時間・全12軸50Hz制御の性能は未検証。

## HW-RS05-VEL-001：位置が安定した状態での速度値の揺らぎ

2026-09-21、ID3のType2速度−0.07248rad/sが旧静止閾値0.05rad/sを超え、右前脚試験を有効化前に中止。
終了時は全3軸の新しい停止状態0・故障0を確認した。試験前後の位置中央値差は全12軸で最大約0.0057°。

続く停止状態のType2記録では、各30点・約3秒で位置幅は0〜0.022°、速度最大絶対値は約0.091〜0.092rad/s。
別のType17読み取りでも、固定10秒を2回、各軸各50点を記録した。
各区間の位置幅は約0.014〜0.017°、電流0Aだが、速度最大絶対値は0.079〜0.188rad/s、
速度RMSは0.036〜0.053rad/sだった。識別3件・読取1,200件の生受信を再解析し、全フレームが記録と一致した。

RS05マニュアルのType2速度範囲±50rad/sと現行変換式は一致している。
速度量子化幅約0.001526rad/sだけでは、今回の揺らぎの大きさを説明できない。
速度推定のノイズや小さな振動などの区別は未確定。速度値をゼロへ書き換えたり、ギア比や符号を推測で変更したりしない。
静止判定として固定時間窓の位置幅・位置傾き・速度RMSを併用する仕様を実装し、関連39テストを通過した。
これは旧単点判定と意味が異なり、同等の安全性が証明されたという扱いにはしない。

13:36の固定2秒・21点の実機確認では、ID1速度RMSが0.05044rad/sとなり、上限0.05rad/sを超えた。
位置幅はID1・2が0、ID3が約0.022°だったが、判定は不成立のまま保存し有効化前に中止した。
全3軸の停止状態0・故障0を確認済み。判定を通すための取り直し・閾値調整は行っていない。
[判定仕様](rs05-supported-leg-stationarity.md)と[実機準備状況](hardware-readiness-20260921.md)を参照。

その後、保存した手動変位と角度・速度の整合を確認し、支持台上の右前脚相対試験専用のposition-v2を追加した。位置幅・傾き・末尾窓・速度平均を検査し、速度RMS超過は警告として保存する。関連47テストをMac・Jetsonで通過後、3回の限定駆動と停止を確認した。旧判定の不成立はそのまま保持し、他脚や全脚制御へ拡大していない。速度揺らぎの原因と、微小運動・標本間振動の検出限界は残る。

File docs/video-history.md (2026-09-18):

# 実際の録画で見る開発履歴

## 現在の進捗と動画の対応

2026-09-18更新。数値結果は[第37回](l32-evaluation.md)まで公開しています。新しい録画の掲載は第31回A/B/Cまでで、全47本の公開録画・比較MP4を保持しています。第32〜37回の動画を過去動画で代用していません。

[READMEの動画で見る進捗](../README.md#動画で見る進捗)は第1・2・3・10・20・30回です。第1・2回は記録のみ、第3回は実録画ではない[初期の計測比較チャート](media/forward-history.mp4)、第10・20・30回はシミュレーション録画を掲載します。[別の節目一覧](milestone-history.md)には第40回を未実施として残しています。最初に掲載した旧保存番号2197の映像は、第1回の映像とは別です。下の記録は各時点の掲載履歴です。

最初に指定されたCAD画像1点と録画5本から、選択した各回の結果・比較を追加してきました。第31回A/B/Cの14秒比較MP4とGIFを各3点追加した際に、公開実録画・比較MP4は44→47本となりました。GIFはMP4本数へ加算しません。最新は第31回ABC、第30回ABCと第27回A/Bも履歴に保持します。CAD画像は初期版と黄色版の2点で、実測チャート再描画MP4とともに録画本数とは別枠です。以前のダイジェストに掲載した最初・よちよち歩き・第5・10・15・20・25回のメディアは、この動画履歴に保持します。14秒比較は表示用の抜粋で、各欄の全評価時間とは区別します。

第32回は[評価集計と比較図](l27-evaluation.md)を公開しました。動画は未回収・未掲載で、最新の公開動画は第31回のままです。第32回掲載時点の32試行と録画・比較MP4の47本、実測チャート再描画MP4の1本を別集計します。

## 対応する段階と結果

| 指定ファイル | 対応する段階 | 結果・解釈 |
|---|---|---|
| `type00.png` | 既存のCAD外観画像<br>[CAD画像](media/cad-type00.png) | 設計イメージ。実機写真・歩行結果・最新学習モデルの証拠ではない |
| `assembly_preview.png` | 黄色・黒の全体CAD更新版（2026-09-14）<br>[README先頭のCAD画像](media/cad-yellow-assembly-20260914.png) | 脚・取手・上部を黄色、Body・顔を黒へ。B02/B04/B06/B08のcandidate_v3補強を反映。以降の共通底板・顔固定・左右連結部r2・足先r3は別部品改訂で、この全体図への統合は示さない |
| `joystick_v3_iter2197_left (1).mp4` / `joystick_v3_iter2197_left.mp4` | 旧形状の保存番号2197・左移動<br>[元MP4](media/archive-joystick2197-left.mp4) · [GIF](media/archive-joystick2197-left.gif) | 2つの名前は同一内容。当時の別評価では速度・姿勢の9条件を満たしたが、後の足別診断は15mm以上の完了足上げが全脚0回 |
| `dev250_left_iter0250.mp4` | 形状・接触表現を更新した別モデルの保存番号250<br>[元MP4](media/archive-dev250-left.mp4) · [GIF](media/archive-dev250-left.gif) | 同じ方策の別4環境・12秒診断で、左指令5cm/sに対して平均約0.16cm/s。全脚の完了足上げ0回 |
| `left.mp4` | B0・初期立位基準の左移動指令<br>[元MP4](media/baseline-left.mp4) · [GIF](media/baseline-left.gif) | 立位を維持するが、全脚の完了足上げ0回 |
| `preview (1).mp4` | 第4回H04・保存番号599の前進評価<br>[元MP4](media/h04-forward.mp4) · [GIF](media/h04-forward.gif) | 12秒完走。世界X速度平均約0.85cm/s、15mm足上げ4/4/4/1回。H03に対して速度は退行 |
| `four_directions_final249_12s_labeled.mp4` | 第5回L00・保存番号249の4方向評価<br>[元MP4](media/l00-four-directions.mp4) · [GIF](media/l00-four-directions.gif) | 方向成分平均は前10.37・後5.90・左4.89・右7.98cm/s。後脚不足・滑り・偏向が残る |

先頭の旧2本について、診断の数値は動画そのものと同一サンプルではありません。原動画と診断が同一チェックポイント・方策に対応することを記録から確認しています。短い動画の見た目だけで、実機への移行や歩行の合格を主張しません。画像・録画に映る製品や部品の権利を、本プロジェクトの独自成果とは扱いません。

## 日付と回数

旧2本の対応実験記録日は2026-09-08（日本時間）ですが、元動画ファイルの正確な撮影時刻は未確定です。B0の評価は9月8日、H04は9月9日。L00は9月9日に動画結果を確認しました。CAD画像の作成日はここでは確定していません。

これらは開発順を示す参考履歴で、モデル・指令・物理設定が異なります。旧2197・旧250を直近系列の実験回数へ混ぜず、H04・L00を二重に数えません。B0とCAD画像も改善回数へ加算しません。2197・250・599・249は保存番号で、改善ループ回数とは別です。全開発の通算回数は引き続き未確定です。

## 動画の扱い

最初に指定された5本の元MP4は指定ファイルと完全に同じバイト列です。その5本はいずれも50fpsで、長さは順に5.98秒、11.98秒、12秒、12秒、12秒です。短い2本を12秒に伸ばしたり、見栄えのよい区間だけを切り出したりしていません。

最初の5本のGIFは480×270へ縮小し、原則5フレームごとと最後の1フレームを表示します。元の時刻間隔を表示時間へ反映し、全体の長さを維持しています。補間・再生速度の変更・画像の切り抜き・動作の描き直しはありません。細かい足上げや接地は50fpsの元MP4と評価記録で確認してください。MP4リンクはGitHubのファイルページへ進み、Rawから元ファイルを開けます。

原本・変換後のSHA、元フレーム番号、表示時間は[個別メディア台帳](../evidence/recording-publication.json)、実験との対応は[履歴JSON](../evidence/video-history.json)にあります。接続先、認証情報、編集可能なCADやモデルファイルは同梱していません。[公開範囲](publication-scope.md)を参照してください。

## L05・第10回の結果動画

L05の4方向・全区間プレビュー

[元MP4・600フレーム・50fps・12秒](media/l05-four-directions.mp4)。ユーザーが今回の結果動画のGitHub掲載を追加指定しました。最終499方策の前後左右を、全区間・等速のまま並べています。動画冒頭の2秒の始動を含み、成功部分だけの編集はしていません。

前16.54・後6.23・左8.05・右6.54cm/sは各12秒の固定世界軸変位から算出。L00の元速度平均と同じ算出法では、L05は前16.57・後6.20・左8.01・右6.60cm/sです。モデルと指令条件が異なる履歴比較で、20cm/sや歩行品質の合格とはしません。後左脚の足上げ不足、後進の後脚の滑り、右移動の約49.7度の向きずれが残ります。L05は既存の第10回に対応し、動画掲載で第11回とは数えません。

## L06・第11回の結果動画

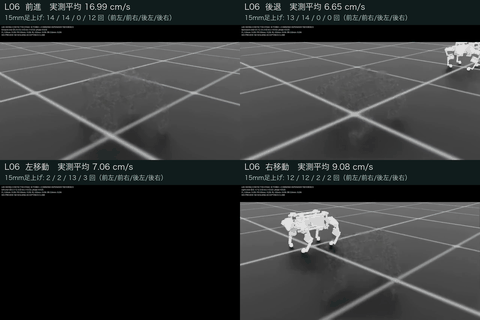
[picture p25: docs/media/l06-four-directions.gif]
L06・全12秒の4方向プレビュー


[元MP4](media/l06-four-directions.mp4) · [評価結果とL05比較](l06-evaluation.md)。ユーザーが今回の評価動画とGitHubコミットを指定したため追加しました。前16.99・後6.65・左7.06・右9.08cm/s、前進の後左15mm足上げ0回。第11回の結果で、動画追加自体は新しい改善ループに数えません。

## L07・第12回の再設計評価

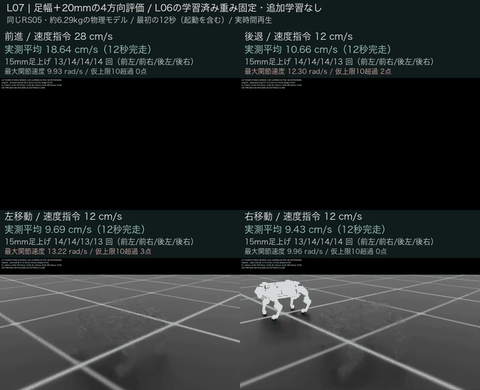
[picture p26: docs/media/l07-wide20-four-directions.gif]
L07・20mm足幅案の四方向、全12秒


[4方向の元MP4](media/l07-wide20-four-directions.mp4) · [前進の足幅比較](media/l07-forward-stance-comparison.mp4) · [接触停止を含む歩幅比較](media/l07-forward-stride-failures.mp4) · [結果と判断](l07-evaluation.md)

今回の評価後、ユーザーがGitHub掲載を指定した3本です。学習済み方策を固定した15ケースを第12回L07としてまとめ、追加学習は0更新。前進18.64cm/sは従来形状の20mm足幅案の結果です。後退・左の仮速度上限超過を映像にも表示し、全方向共通の制御には採用していません。新形状の成果へ流用しません。

3本とも600フレーム・50fps・12秒を保ち、停止後のパネルを明示します。今回のGIFは480×390で、元の時刻間隔と最終フレームを保つ縮小版です。CAD・モデル・第三者部品データは追加公開しません。

## L08・第13回の学習評価

[4方向MP4](media/l08-four-directions.mp4)・[全区間GIF](media/l08-four-directions.gif)・[前進の学習前後比較](media/l08-forward-progress.mp4)。500更新後、前進29.93cm/s。30cm/s未達と左移動48.74°の偏向を表示しています。2本を改善2回とは数えません。[条件と測定値](l08-evaluation.md)。

## L09・第14回の学習評価

L09・4方向の全12秒プレビュー

[4方向MP4](media/l09-four-directions.mp4) · [第14回の元評価](l09-evaluation.md)。500更新後、前31.87・後10.59・左7.63・右9.23cm/s。前進の短区間基準達成に加え、後進・左の向きと左右速度の未達を表示しています。L08と比べた後進・左右の初期状態差も結果に残しました。

モンタージュは元600フレーム・50fps・12秒を保っています。上端に残っていた前回の回数表記を第14回へ訂正し、初期の黒画面・描画残像は残しました。GIFは全区間の時間を保つ縮小プレビューです。

## L10・第15回の学習評価と比較用L09

L10・6方向の全12秒プレビュー

[最終6方向MP4](media/l10-six-directions.mp4) · [同じ初期化のL09比較4方向MP4](media/l10-matched-l09-four-directions.mp4) · [条件・測定値・未達](l10-evaluation.md)

最終6方向は前32.16・後10.67・左8.36・右11.65cm/s。左右旋回の向き変化は+106.78°/−148.29°、指令方向の平均角速度は0.155/0.216rad/sです。前進・後進・右移動の3/6ケースが全開発基準を満たしました。左速度と左右旋回の位置保持は未達で、最大位置ずれ28.3/19.2cmも表示しています。

比較動画は、第15回内でリセット時の初期状態をそろえ、元L09制御・方策を評価し直した4方向です。**上の第14回の元L09動画とは別の評価**で、元結果を置き換えません。前進の前左足滑りはこの比較用L09から4.74→14.03cmへ増加しています。

2本とも600フレーム・50fps・12秒。元10動画の全6,000フレームを時間順に使い、始動2秒と冒頭の黒画面・薄い残像も残しました。最初・中間・最後の静止画で表示を確認していますが、全フレームの人による目視検査ではありません。6方向GIFは全区間の時間を保つ縮小版です。

L09の1本とL10の2本を加え、既存12本から計15本になりました。実測チャートの再描画動画は、この実録画・比較動画の本数と区別します。公開や比較動画の追加を新しい改善回数には数えません。

## L11・第16回の学習評価と同条件の親L10

L11・6方向の全12秒プレビュー

[最終6方向MP4](media/l11-six-directions.mp4) · [同条件の親L10比較6方向MP4](media/l11-matched-l10-six-directions.mp4) · [条件・測定値・未達](l11-evaluation.md)

前42.0179・後12.1189・左6.9422・右11.5098cm/s。指令44cm/sに対し、前進40cm/sと前進の全開発基準を達成しました。前進・後進・右の3/6ケースが全基準達成。左移動の向き+29.5511°、前右滑り17.9163cmと、速度の未達を残しています。左右旋回は指令方向平均0.214110/0.261625rad/s、最大位置ずれ41.4868/24.7780cmで位置保持が未達です。

比較用の親L10は、L11と同じ制御・指令・初期状態で撮り直した6方向です。前進は同じ44cm/s指令で35.7555→42.0179cm/s。**第15回当時の指令36cm/s・前進32.1595cm/sとは別の比較群**で、元のL10結果を置き換えません。学習・評価を含むジョブは09/09 22:36:26 JSTに終了し、回収と映像等の後処理は09/10に完了しました。

2本とも600フレーム・50fps・12秒。元12動画の7,200フレームと、公開する合成2動画の1,200フレームを全てデコードしました。合成動画の最初・中間・最後、計6枚の静止画で表示を確認しています。冒頭の黒画面・残像・元の撮影端での機体切れは除去していません。全フレームの人による目視検査ではありません。GIFは全区間の時間を保つ縮小プレビューです。

今回2本を追加し、実録画・比較動画は15本から17本になりました。再描画チャートは別の本数です。第16回の学習・評価を一組として数え、比較撮り直し・動画の追加・第17回の準備を新たな完了回数には加えません。

## L12・第17回の評価と同条件の親L11

第17回の6方向。前進終了後は黒パネル

[最終MP4](media/l12-six-directions.mp4) · [同条件L11親MP4](media/l12-matched-l11-six-directions.mp4) · [結果](l12-evaluation.md)

各600フレーム・50fps・12秒の比較枠です。前進原本は557フレーム・11.14秒で終了し、残り43フレームは「以後の映像なし」。終端原本画像は自動リセット後描画の可能性があり、失敗判定はリセット前記録を使っています。GIFは終端557・最初の黒558を含め元の時刻で表示します。第17回の公開時点では、追加2本で実録画・比較動画は19本、結果を整理した有限試行は17回でした。

## L13・第18回：歩行6方向の評価

第18回・6方向の全12秒プレビュー

[最終6方向MP4](media/l13-six-directions.mp4) · [第18回の結果・確認範囲](l13-evaluation.md)

1000更新後の最初の12秒を、600フレーム・50fpsで示します。前進40.2521・後進10.0692・左10.0871・右11.3432cm/s、左右旋回0.238681／0.229853rad/s。既存の開発基準は6/6が通過しました。始動の2秒、冒頭の黒画面と半透明描画を保持しています。

追加の下腿床離隔5mm目標は最小4.783386mmで一部未達です。左移動の前後漂流23.4425cm、後進の横漂流14.7335cm、学習後の実測姿勢によるnative CAD検査の未実施も結果に残しています。短い動画の完走を、PLA部品や回収用取手の実機強度の検証には使いません。

## L14・第19回：指定model500の伏せ・起立評価

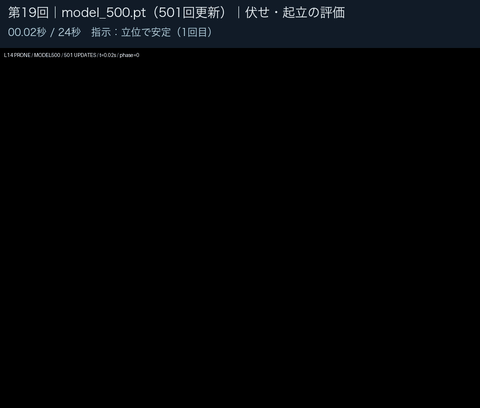
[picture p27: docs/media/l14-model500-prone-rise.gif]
第19回・501更新モデルの全24秒プレビュー


[伏せ・起立MP4](media/l14-model500-prone-rise.mp4) · [第19回の結果・残課題](l14-evaluation.md)

元の1000更新計画はユーザー指示で途中終了し、指定されたiteration500＝**501更新後**のモデルを評価しました。停止直前の最後のログiteration613や、600更新時点の進捗集計とは別のモデルです。評価での追加学習は0回。

全1200フレーム・50fps・24秒を収録し、元画像の上側に日本語の指示phase説明を加えました。伏せ2秒と起立後の四足保持2秒をそれぞれ2回達成し、禁止接触・速度超過は0標本。向き+47.0648°、平面位置11.4919cm、負荷モデルh≈1が残課題です。方位・位置は登録合否に含まれておらず、hは実測温度ではありません。

冒頭の黒フレームと最後の自動リセット後の立位を保持し、動画内でも終端リセットを明記しています。保持成功は、終端描画ではなくリセット前の400Hz記録で判定しました。字幕付きMP4の1200フレームを全復号済みで、GIFは24秒の時刻を保つ縮小プレビューです。

L13とL14のMP4を1本ずつ追加した時点で、実録画・比較動画は19本から21本、直近系列は19回でした。CAD画像1点と再描画チャートは別枠です。GIF、動画の公開、同じ学習の途中モデル評価を追加ループには数えません。次節は、その後に実施した第20回の記録です。

## L15・第20回：500更新後のその場での伏せ・起立評価

[最終model499・24秒MP4](media/l15-model499-stationary-prone.mp4) · [全区間GIFプレビュー](media/l15-model499-stationary-prone.gif) · [第20回の条件・測定値・未達](l15-evaluation.md)

L14の指定モデルを起点に500更新を実施し、最終iteration499を評価しました。学習終了は09/10 20:34:19 JST、24秒評価の終了は20:47:09 JSTです。前回のmodel500＝501更新後とは別の保存モデルで、今回追加した更新数は500です。

全1200フレーム・50fps・24秒の評価録画です。伏せ2秒保持を2回達成した一方、第2起立は元の高さ条件を満たす連続区間が1.9375秒／必要2秒でした。全区間の最大方位ずれ21.4577°と最大平面位置ずれ6.9344cmは、それぞれ5°・5cm以内の目標を超えました。起立保持中の最大傾き7.9249°も5°以内に届かず、強化した起立高さ条件と合わせて**その場動作の基準は未達**です。

判定は終端の描画から推測せず、リセット前の400Hz記録9600標本を使いました。この24秒評価中の禁止接触・速度超過は0標本ですが、学習中には速度超過1標本がありました。駆動負荷hは約1で、実測温度ではありません。72秒評価は24秒の基準未達により明示的にスキップし、長時間の達成結果はありません。

L15のMP4を1本追加し、実録画・比較動画は22本、H01〜H04とL00〜L15の直近系列は20回になりました。第20回終了時点では、設計修正と次の学習を次回へ持ち越していました。最新の配色指定や実物搭載部の検討を、この評価済みモデルの形状・強度検証済みの成果とは扱いません。この時点ではジャンプ・後ろ足2本立ちは未学習でした。

READMEの映像ダイジェストは最初の掲載動画（旧形状・保存番号2197）、よちよち歩き（第4回H04）、第5・10・15・20回を表示します。よちよち歩きは既存H04の表示名で、実験回数へ追加しません。最初の動画は直近20回より前の参考記録です。各回の詳細と元動画はこの履歴に保持します。第20回のGIFは全24秒を480×360で縮小表示する241フレームのプレビューで、冒頭の黒画面と終端のリセット注意表示を残しています。動画やプレビューの公開を新しい実験回数へ加算しません。

## L16・第21回：機器配置を更新した伏せ・ジャンプ評価

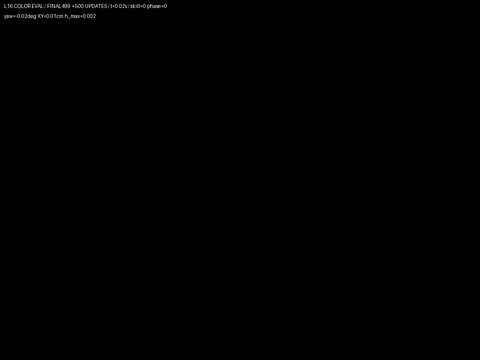
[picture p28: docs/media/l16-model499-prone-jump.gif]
第21回・伏せとジャンプの全24.2秒プレビュー


[最終model499・元MP4](media/l16-model499-prone-jump.mp4) · [第21回の条件・測定値・未達](l16-evaluation.md)

中央バッテリー配置と取付部を更新したモデルで、500更新・4,096,000遷移の学習を実施し、最終iteration499を評価しました。学習は2026-09-10 22:38:34 JSTに完了。通常評価と同じモデル・生計測の配色評価を掲載しており、配色変更による追加学習は0回です。第19回のmodel500＝501更新後とは区別します。

第1周期の伏せ2秒保持と四足復帰2秒保持は達成しました。一方、四足復帰の追加目標である高さ誤差±15mmは未達。ジャンプの準備支持は成立しましたが、踏切・飛行の目標区間400標本で四足同時に0.5N以下となった標本も、四足同時に5mm以上離れた標本も0でした。合格する離床・着地は確認できず、**ジャンプと総合基準は未達**です。

40秒予定の評価は、第2周期の伏せへ降下中に右前脚の太ももで禁止接触を検出し、24.2秒で終了しました。禁止接触は3標本、最大28.48N。合力センサーから接触相手は判別できず、床との接触とは断定しません。2周期完遂と第2起立の改善は確認できていません。最大方位ずれ21.26°、最大平面位置ずれ10.59cmは、5°・5cm以内の目標を超えました。評価中の関節速度は最大9.219rad/s、10rad/s超過0ですが、学習探索中には超過25関節標本・最大11.100rad/sがありました。

掲載MP4は元動画と同一バイト列の1210フレーム・50fps・24.2秒です。未記録の残り15.8秒を補いません。冒頭の黒画面と、最終画像が自動リセット後の可能性を示す赤い注意表示を保持しています。判定はリセット前の計測に基づき、最後の立位描画を成功の証拠にしません。GIFは毎5フレームと最後の1209番（0始まり）を使う243枚、480×360、全24200msの等速プレビューです。補間、区間の切り抜き、成功場面だけの選択、速度変更はありません。

L16のMP4を1本追加し、実録画・比較動画は22本から23本、H01〜H04とL00〜L16の直近系列は21回になりました。GIF・配色評価・公開作業は追加ループに数えません。機体とタスクが異なるため、第20回からの単純な改善率は出しません。動画内の配色確認と、別工程のFusion最終色版CAD保存、実機でのPLA強度検証も区別します。

## L17・第22回：3条件各500更新の左前足による挨拶

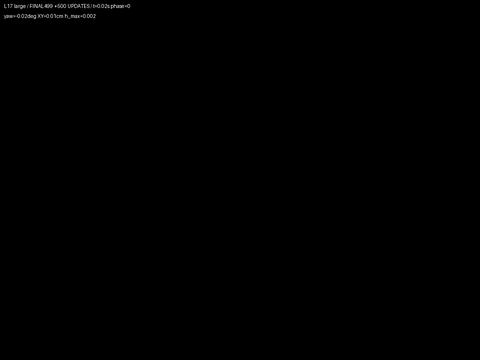
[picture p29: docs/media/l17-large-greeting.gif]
第22回・大条件の全28秒プレビュー


[3条件の同期比較MP4](media/l17-greeting-comparison.mp4) · [小条件](media/l17-small-greeting.mp4) · [中条件](media/l17-medium-greeting.mp4) · [大条件](media/l17-large-greeting.mp4) · [測定値と課題](l17-evaluation.md)

同じL16親から小・中・大をそれぞれ500更新し、3本の最終model499を28秒ずつ評価しました。1本を1500更新した結果ではありません。各MP4は1400フレーム・50fps・28秒で、比較動画も同じ時刻で3条件を並べます。全処理は2026-09-11 09:00:03 JSTに終了しました。

| 条件 | 成立往復数／4 | 動作成立周期／2 | 四足復帰の連続保持 | 最大方位ずれ | 最大XYずれ | 総合 |
|---|---:|---:|---|---:|---:|---|
| 小 | 0 | 0 | 2.000／2.000秒 | 10.874° | 6.100cm | 未達 |
| 中 | 4 | 0 | 1.985／1.980秒 | 3.664° | 7.112cm | 未達 |
| 大 | 4 | 2 | 2.000／2.000秒 | 5.827° | 7.757cm | 未達 |

大条件は左前足を2往復振って四足へ戻る動作を2周期とも達成しました。ただし基準は全区間で方位5°以内・XY5cm以内で、最終位置が2.888cmへ戻っても途中の7.757cmを見落とせません。中条件の15ms／20msの復帰不足も2秒へ丸めません。3条件とも28秒完走、手振りの全8秒で左前足離床と残3足支持を満たし、評価中の禁止接触・速度超過は0でした。学習中の探索では禁止接触があり、評価の0と区別します。

大条件のseed42・43・44は400Hz生計測のバイト列が完全同一でした。同じ決定的条件の再現性を示しますが、初期姿勢・外乱などを変えた頑健性試験3例ではありません。終端の描画を復帰成功の根拠にはせず、保持はリセット前の400Hz計測で判定しています。

脚・取手は黄色、Body・底板・固定具・顔枠は黒、仮IMUは赤の評価映像です。物理形状と質量はL16から固定しており、新しいCAD完成・PLA強度検証・実機での成立を示すものではありません。今回は伏せとジャンプを実行していません。

この4本を追加した第22回終了時点では、実録画・比較動画は27本、直近系列は22回でした。3条件・比較動画・GIF・追加seed評価を別の実験回数に加算しません。続く第23・24回の記録を以下に示します。

## L18・第23回：前足を高く上げる挨拶

第23回・高い挨拶の全36秒

[最終model499・元MP4](media/l18-model499-high-wave.mp4) · [条件・実測値・未達](l18-evaluation.md)

L17大条件の行動平均を基に500更新し、18秒×2周期を評価しました。学習は09/11 10:24:26 JST、評価は10:28:31 JSTに完了。左前足の床離隔は最低153.2898mmで、手振りの全8秒にわたり150mm以上を保ち、4往復と四足復帰各2秒を達成しました。最大方位4.6227°は5°以内ですが、最大XY6.5507cmが5cmを超えて総合未達です。終端0.9136cmへ戻ったことだけで成功とは判定しません。

MP4は1800フレーム・50fps・36秒の原本と同一バイト列です。GIFは毎5フレームと最後を用いた361枚・480×360・全36000ms。全MP4/GIFフレームをデコードし、冒頭・途中・終端の選択画像を目視しました。黒い冒頭フレームと終端リセットの注意表示を保持し、補間・切り抜き・速度変更は行っていません。保持の判定はリセット前の400Hz記録に基づきます。

評価中の禁止接触・速度超過は0ですが、学習探索中には速度超過68関節標本と接触がありました。h最大0.6194は評価時の負荷モデル値で、実測温度ではありません。この1本で実録画・比較動画は28本、直近系列は23回です。

## L19・第24回：浅いお座りと四足立位への復帰

第24回・お座りと立位復帰の全32秒

[最終model499・元MP4](media/l19-model499-sit.mp4) · [条件・実測値・合否](l19-evaluation.md)

前回の先頭81入力の行動平均を保持し、新しい座位の8入力列をゼロから開始して500更新しました。学習は09/11 11:34:17 JST、評価は11:38:02 JSTに完了。鼻上げ12.0883〜12.5752°と後腰低下56.7061〜60.9998mmを伴う浅いお座りで、水平な伏せや後ろ足だけの立位ではありません。座位と四足復帰を2周期実行し、全4保持窓の各3秒で条件を満たしました。最大方位1.5359°・最大XY3.3577cmで全登録基準を通過しています。

MP4は1600フレーム・50fps・32秒の原本と同一です。GIFは321枚・480×360・全32000msで全区間を保ちます。全フレームをデコードし、選択した時刻の画像を目視確認しました。自動リセット後かもしれない最後の立位描画を成功の根拠にせず、12800個のリセット前400Hz標本をローカルで同じ登録済みNumPy処理へ通し、206比較項目の一致を確認しました。独立した別アルゴリズムによる再判定ではありません。

評価中の禁止接触・速度超過は0、最大関節速度3.0301rad/s、最大出力1.9105Nm、負荷h最大0.0803です。学習中の接触終了、単一seed・平面32秒という範囲を残しています。実機、PLA強度、外乱に対する頑健性、9モーション全体の合格とは扱いません。

第24回終了時点で、実録画・比較動画は29本、直近系列は24回でした。GIF・検証・公開作業は別の完了試行へ加算しません。READMEの履歴ダイジェストは最初・よちよち歩き・第5・10・15・20回の6点を維持します。

## L20・第25回：9動作を3×3で同時表示

4独立方策の9動作を個別に評価しました。本学習の実行累計はR2の163＋R3歩行157＋R4の180＝500更新です。500更新の予算に到達しました。保存モデルに残った第25回の方策系列は計488更新分で、R2で実行した12更新は未保存です。登録した全基準の合格は2/9件、未達は7件。同じD16で評価した元の親+0更新は9/9件を受領し、そのうち合格3件。最終は2/9件が合格です。前進の最初の評価区間の速度は39.3468cm/sでした。

第25回・9動作の14秒比較。手振りとお座りは周期途中まで、終了した枠はカラー静止表示

[9分割MP4・14秒・50fps](media/l20-nine-motions.mp4) · [判定・同D16親との比較](l20-evaluation.md)

| 位置 | 動作・原動画 | 実測録画時間 | 全登録基準 |
|---|---|---:|---|
| 1段目・1列目 | [前進](media/l20-forward.mp4) | 12.00秒 | 未達 |
| 1段目・2列目 | [後進](media/l20-backward.mp4) | 12.00秒 | PASS |
| 1段目・3列目 | [左移動](media/l20-left.mp4) | 12.00秒 | 未達 |
| 2段目・1列目 | [右移動](media/l20-right.mp4) | 12.00秒 | 未達 |
| 2段目・2列目 | [左旋回](media/l20-turn-left.mp4) | 12.00秒 | 未達 |
| 2段目・3列目 | [右旋回](media/l20-turn-right.mp4) | 12.00秒 | 未達 |
| 3段目・1列目 | [伏せ](media/l20-prone.mp4) | 24.00秒 | 未達 |
| 3段目・2列目 | [高い挨拶](media/l20-wave.mp4) | 36.00秒 | 未達 |
| 3段目・3列目 | [浅いお座り](media/l20-sit.mp4) | 32.00秒 | PASS |

個別9本と比較1本の計10本を追加し、実録画・比較動画は39本になりました。実測チャートの再描画MP4は別枠の1本です。3×3比較は14秒です。6方向移動は各12秒の全区間、伏せは最初の1周期12秒を等速で表示します。手振りは18秒周期、お座りは16秒周期の先頭14秒までで、両者の第1周期は最後まで表示しません。表示区間の終了後は、その区間の最後のフレームを元のカラーで静止表示し、終了時刻とSTILLを添えます。この静止表示は実動作や保持成功の時間へ数えません。各プレビュー画像内の左上、元の黒いcaption欄より下の背景へ、黒い縁取りの明るい水色で英語動作名を大きく重ねます。画面の合否と表の数値は、個別原動画の全評価区間（移動12秒、伏せ24秒、挨拶36秒、お座り32秒）に基づきます。上表は全原動画の時間とリンクを保持しています。4方策を同時実行した一つの機体や、同一エピソード内の連続切替を示す映像ではありません。各原動画の最初の黒いフレームや終了時の描画も残し、停止前の実測記録で判定しました。

## L21・第26回：数値結果の追加

500更新後の9動作評価は6/9件合格でした。今回、第26回の新規録画は掲載せず、[結果と出典SHA](l21-evaluation.md)を追加します。動画の有無で試行回数を増減しません。

## L22・第27回：独立A/Bの9動作比較

同じ親・seed42からA/B各500更新を実行し、各条件6/9件が全基準合格でした。1方策を1000更新した結果ではなく、A/Bの合格を合成した方策でもありません。[条件と測定値](l22-evaluation.md)。

第27回A・全評価6/9合格の14秒プレビュー

[AのMP4](media/l22-a-nine-motions.mp4)

第27回B・全評価6/9合格の14秒プレビュー

[BのMP4](media/l22-b-nine-motions.mp4)

各MP4は960×800・50fps・700フレーム・14秒です。全18原録画は生成時にSHA照合と全復号を確認し、選択した比較MP4は同一バイト列で掲載しました。GIFは720×600・141枚・14000msで、シアンの英語ラベルを保持します。

6方向は各12秒、伏せは第1周期12秒を表示し、短い欄は最後のカラー画像を静止表示します。B前進は速度超過で8.92秒終了し、その終端の空床画像とTERMINATED表記を残します。挨拶と座位は18秒／16秒周期の先頭14秒で途中までです。FULL EVALの合否は全評価（12／24／36／32秒、早期終了時はその実区間）に基づき、静止表示を動作保持時間には数えません。

この2本を掲載した時点で実録画・比較動画は41本、直近系列は27回でした。READMEの最初・よちよち歩き・第5・10・15・20回は維持します。元の実物写真・動画確認用の静止画・CAD・重みは追加公開しません。

## L23・第28回：500更新・7/9合格、動画は未掲載

A条件は2026-09-12 16:03:51 JSTに500新更新と9動作評価を完了しました。内訳は歩行150・伏せ250・挨拶100・お座り0更新で、お座りは既存の親を保持しています。歩行6方向とお座りの計7/9件が登録基準に合格し、伏せと挨拶は未達です。[第28回の結果](l23-evaluation.md)。B条件は開始に必要な残り7,200秒を確保できず未実行で、今回の実更新合計は500です。

保存先で原動画9本のSHAと動画メタデータを確認しましたが、手元への全長原動画の取得は0/9本です。14秒比較のCPU編集は起動したものの、完成・全復号・目視確認と取得は未完了です。第28回のMP4/GIFは今回掲載せず、上の第27回A/Bを第28回の映像として使いません。

第28回は同じD17を用い、形状・物性・STLを変更していません。4つの独立方策の9評価であり、単一方策の連続切替や実機成功を示しません。第28回終了時点の直近系列は28回で、公開する実録画・比較動画は41本でした。その時点では次の学習は未開始でした。

## L24・第29回／L25・第30回：先行した数値公開の記録

第29・30回はそれぞれA/B/Cの独立3条件を各500更新、各回計1500新更新として完了しました。各条件とも歩行6方向とお座りの7/9件が合格し、伏せと高い挨拶は未達です。[第29回の結果](l24-evaluation.md)・[第30回の結果](l25-evaluation.md)。

第30回の伏せはB/Cで2回とも連続2秒保持と四足復帰を達成しましたが、Cの最大XY57.52mm・方位ずれ21.38°が残りました。挨拶は足先150mm以上・4往復・四足復帰を維持し、最大XYはCで63.02mmでした。先行した数値公開ではMP4/GIFを追加せず、その時点で動画は別途回収・検査中でした。数値の全評価区間と14秒の表示用ダイジェストは別です。

先行した数値公開時点では直近系列30回・公開実録画41本でした。以下の第30回動画追加は新しい試行に数えません。その数値公開時点では第31回の学習は未開始でした。

## L25・第30回：A/B/Cの14秒3×3比較

[A・14秒MP4](media/l25-a-nine-motions.mp4) / [GIF](media/l25-a-nine-motions.gif) · [B・14秒MP4](media/l25-b-nine-motions.mp4) / [GIF](media/l25-b-nine-motions.gif) · [C・14秒MP4](media/l25-c-nine-motions.mp4) / [GIF](media/l25-c-nine-motions.gif)

各条件を別々の3×3比較として並べます。6方向移動は各12秒の全区間、伏せは24秒評価の第1周期12秒を表示します。挨拶は18秒周期、お座りは16秒周期の先頭14秒までで、両者の第1周期は途中までです。12秒で表示区間が終わる欄は、その区間の最後のフレームをカラーで静止表示し、終了時刻とSTILLを示します。この静止時間は実動作や保持成功へ加算しません。

各プレビュー画像内の左上、元の黒いcaption欄より下の背景に、黒い縁取りの明るいシアンで英語動作名を重ねます。英語名はForward、Backward、Move Left、Move Right、Turn Left、Turn Right、Lie Down、Wave、Sitです。

FULL EVALの合否と本文の測定値は、各原評価の全区間（移動12秒、伏せ24秒、挨拶36秒、お座り32秒）に基づきます。14秒の表示から2周期の成立や全区間の最大値を再判定しません。各条件7/9合格、伏せ・挨拶の総合未達、1500主更新と4専門方策の区別は不変です。単一方策での連続切替や、実機での成功を示す動画ではありません。

## L26・第31回：ABCの14秒比較と途中終了

[A・14秒MP4](media/l26-a-nine-motions.mp4) / [GIF](media/l26-a-nine-motions.gif) · [B・MP4](media/l26-b-nine-motions.mp4) / [GIF](media/l26-b-nine-motions.gif) · [C・MP4](media/l26-c-nine-motions.mp4) / [GIF](media/l26-c-nine-motions.gif)

各条件500主更新、計1500主更新後の9動作を別々の3×3で表示します。全条件7/9合格で、新たな合格動作は0。MP4は960×800・50fps・700フレーム・14秒、GIFは対応する14秒全区間の縮小表示です。原録画と編集物を区別し、原本SHA・全復号・表示確認は個別台帳へ登録します。[選択した評価結果](l26-evaluation.md)。

移動6方向は12秒、A伏せは第1周期12秒、B/C伏せは実終端9.68/9.74秒までです。表示終了後はその最後のカラー画像を保持し、STILL/TERMINATEDを示します。挨拶とお座りは18/16秒周期の先頭14秒で途中まで。英語名は各シミュレーション画像左上の背景へシアンで表示します。

Cの挨拶は23.18/36秒で禁止接触終了し、14秒抜粋には実終端が映りません。そのため映像表示中も全記録の途中終了を明記します。FULL EVALの合否は元評価によるものです。終端描画に自動リセット後の姿勢・空の背景があっても、安定復帰・成功姿勢の証明とはせず、カラー静止時間も保持成功へ加算しません。

原27動画は検証しましたが、今回の公開対象は表示用ABC比較MP4/GIFの6ファイルです。原計測配列・モデル重み・検査用静止画は追加しません。既存44本と履歴7件を保持し、実験系列は31回、録画・比較MP4は47本として別集計します。

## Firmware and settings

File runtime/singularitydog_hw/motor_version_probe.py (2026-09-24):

"""Bounded RS05 stop-and-version probe, fixed IDs1..12; NOT pure read-only.

Each ID must match its expected UID, acknowledge an ordinary Type4 stop with
canonical Type2 mode0/fault0, then receives ONE Type4 version query. Only the
documented 00 c4 56 Type2 reply is a version. Raw bytes3..6 are retained without
guessing semantic firmware numbers; byte7 is unspecified and retained.

Primary source: RS05User Manual260713.pdf, printed English pages45--46
(PDF pages47--48), SHA256 recorded in MANUAL below. Boot continuity and physical
readiness belong to the caller. No enabling, settings, zero/save, Type26 fallback
or automatic retry exists. A timeout poisons the session before later IDs.
"""
import argparse
from datetime import datetime, timezone
import hashlib
import json
import os
from pathlib import Path
import signal
import time

from . import can_readonly as codec
from . import rs05_trial_protocol as protocol
from . import can_timing_probe as timing

IDS = (1, 2, 3, 4, 5, 6, 7, 8, 9, 10, 11, 12)
TIMEOUT_NS = 250_000_000
GAP_NS = 5_000_000
DRAIN_NS = 50_000_000
MAX_RUN_NS = 15_000_000_000
VERSION_PAYLOAD = b"\x00\xc4" + bytes(6)
VERSION_PREFIX = b"\x00\xc4\x56"
MANUAL = {"url": "https://github.com/RobStride/Product_Information/blob/main/Product%20Literature/RS05/RS05User%20Manual260713.pdf",
          "sha256": "1b2c61a6daa8331b9a348455005d10d6e425165c22e6f64c39cbca33f6360e82",
          "printed_english_pages": [45, 46], "pdf_pages_one_based": [47, 48]}


class VersionUnknown(TimeoutError):
    """The sole version query had no matching version before its deadline."""


def _require(condition, reason):
    if not condition:
        raise ValueError(reason)


def version_request(motor_id):
    _require(type(motor_id) is int and motor_id in IDS, "ID outside fixed version-probe scope")
    can_id = (4 << 24) | (codec.HOST_ID << 8) | motor_id
    return b"AT" + ((can_id << 3) | 4).to_bytes(4, "big") + b"\x08" + VERSION_PAYLOAD + b"\r\n"


def decode_version(frame, motor_id):
    _require(motor_id in IDS and type(motor_id) is int, "ID outside fixed version-probe scope")
    protocol._reply(frame, 2, motor_id)  # Canonical29-bit AT, flags4, DLC8, source/destination.
    _require(frame.data[:3] == VERSION_PREFIX, "Normal Type2 feedback is not a version reply")
    _require(((frame.can_id >> 22) & 3) == 0 and ((frame.can_id >> 16) & 63) == 0,
             "Version reply reports running/reserved mode or fault")
    return {"version_bytes_hex": frame.data[3:7].hex(), "version_bytes": list(frame.data[3:7]),
            "byte_order": "as received; high-order first per manual",
            "semantic_firmware_version": None, "unspecified_byte7": frame.data[7],
            "mode_state": 0, "fault_bits": 0, "raw_frame": frame.record()}


def validate_uids(data):
    _require(isinstance(data, dict), "Expected UID JSON must be an object")
    keys = {str(k) for k in data}
    _require(all(type(k) in (str, int) for k in data) and len(keys) == len(data)
             and keys == {str(i) for i in IDS},
             "Expected UID keys must be all fixed IDs1..12")
    _require(all(isinstance(v, str) and len(v) == 16 and all(c in "0123456789abcdef" for c in v)
                 for v in data.values()) and len(set(data.values())) == len(data), "Invalid/duplicate UID")
    normalized = {int(k): value for k, value in data.items()}
    return {mid: normalized[mid] for mid in IDS}


def make_plan():
    return {"ids": list(IDS), "per_id_sequence": ["fresh_identity", "ordinary_stop_confirmed", "version_once"],
            "allowed_can_types": [0, 4], "max_write_attempts": 36, "max_version_queries": 12,
            "version_request_payload_hex": VERSION_PAYLOAD.hex(), "ordinary_stop_payload_hex": bytes(8).hex(),
            "reply_timeout_ms": 250, "minimum_after_write_ms": 5, "fresh_boundary_max_ms": 50,
            "max_run_s": 15, "pure_read_only": False, "stop_command_available": True,
            "motor_enabling_available": False, "motion_command_available": False,
            "settings_available": False, "automatic_retry": False, "type26_fallback": False,
            "approved_for_runtime": False, "boot_verified_by_tool": False,
            "manual": dict(MANUAL)}


class VersionProbe:
    """One finite session; validated bytes only at the physical write boundary."""
    def __init__(self, port, emit, *, check_interrupt=lambda: None, clock=time.monotonic_ns):
        self.port, self.emit, self.check_interrupt, self.clock = port, emit, check_interrupt, clock
        self.parser = codec.ATParser()
        self.started_ns = self.last_clock_ns = clock()
        self.last_write_finished_ns = None
        self.write_attempts = 0
        self.poisoned = self.collected = False
        self.schedule = [(mid, step) for mid in IDS for step in ("identity", "stop", "version")]

    def _check(self):
        self.check_interrupt()
        now = self.clock()
        _require(type(now) is int and self.last_clock_ns <= now, "Monotonic clock moved backward")
        self.last_clock_ns = now
        if self.poisoned or now-self.started_ns >= MAX_RUN_NS:
            raise RuntimeError("Probe poisoned or total time budget exhausted")
        return now

    def _receive(self, deadline, phase):
        now = self._check()
        self.port.timeout = max(0., min(.002, (deadline-now)/1e9,
                                       (self.started_ns+MAX_RUN_NS-now)/1e9))
        chunk = self.port.read(min(max(self.port.in_waiting, 1), 4096))
        received = self.clock()  # Raw read completion, before emit/parse work.
        if not chunk:
            self._check()
            return [], received
        self.emit({"kind": "version_rx_bytes", "monotonic_ns": received, "phase": phase, "hex": chunk.hex()})
        frames = self.parser.feed(chunk)
        _require(self.parser.discarded_bytes == 0, "Malformed/discarded serial bytes")
        for frame in frames:
            self.emit({"kind": "version_rx_frame", "monotonic_ns": received, "phase": phase, **frame.record()})
            _require(frame.flags == 4 and len(frame.data) == 8, "Noncanonical flags or DLC")
            if frame.kind == 2 and frame.destination == codec.HOST_ID and frame.source in IDS:
                if frame.data[:3] == VERSION_PREFIX:
                    decode_version(frame, frame.source)  # Also rejects fault/running version-shaped packets.
                else:
                    fb = protocol.decode_type2(frame, motor_id=frame.source)
                    _require(fb.mode_state == 0 and fb.fault_bits == 0, "Running mode or fault in Type2 feedback")
            elif frame.kind == 21 and frame.source in IDS:
                raise RuntimeError("Motor fault-detail frame received")
        self._check()
        return frames, received

    def _boundary(self):
        """Discard/log old frames until5ms quiet, within a50ms total drain bound."""
        start = self._check()
        deadline, quiet = start+DRAIN_NS, start+GAP_NS
        if self.last_write_finished_ns is not None:
            quiet = max(quiet, self.last_write_finished_ns+GAP_NS)
        while self._check() < quiet or self.port.in_waiting:
            if self.clock() >= deadline:
                raise RuntimeError("CAN backlog prevents a fresh request boundary")
            frames, received = self._receive(min(quiet, deadline), "pre_send_discard")
            if frames or self.parser.buffer:
                quiet = received+GAP_NS
        _require(not self.parser.buffer, "Partial old frame at request boundary")

    def _exchange(self, motor_id, step):
        self._check()
        _require(self.write_attempts < len(self.schedule)
                 and (motor_id, step) == self.schedule[self.write_attempts], "Invalid request order/count")
        self._boundary()
        wire = (codec.read_request(motor_id) if step == "identity" else
                protocol.stop_request(phase=protocol.TrialPhase.STOP, motor_id=motor_id)
                if step == "stop" else version_request(motor_id))
        allowed = {codec.read_request(motor_id),
                   protocol.stop_request(phase=protocol.TrialPhase.STOP, motor_id=motor_id),
                   version_request(motor_id)}
        _require(wire in allowed, "Outgoing wire not permitted")
        self.emit({"kind": "version_tx_intent", "monotonic_ns": self.clock(),
                   "motor_id": motor_id, "step": step, "hex": wire.hex()})
        started = self._check()
        deadline = started+TIMEOUT_NS
        self.port.write_timeout = .02
        returned = None
        self.write_attempts += 1
        try:
            returned = self.port.write(wire)
        finally:
            self.last_write_finished_ns = self.clock()
            self.emit({"kind": "version_tx_write", "motor_id": motor_id, "step": step, "hex": wire.hex(),
                       "write_started_monotonic_ns": started,
                       "write_finished_monotonic_ns": self.last_write_finished_ns,
                       "expected_bytes": len(wire), "returned_bytes": returned,
                       "deadline_monotonic_ns": deadline})
        _require(type(returned) is int and returned == len(wire), "Partial serial write; no retry")
        while self._check() < deadline:
            frames, received = self._receive(deadline, step)
            if received >= deadline:
                break
            match = None
            for frame in frames:
                if step == "identity" and codec.matches(frame, motor_id, None):
                    value = codec.decode_reply(frame, motor_id, None)
                elif frame.kind == 2 and frame.source == motor_id and frame.destination == codec.HOST_ID:
                    if step == "version" and frame.data[:3] == VERSION_PREFIX:
                        value = decode_version(frame, motor_id)
                    elif step == "stop" and frame.data[:3] != VERSION_PREFIX:
                        fb = protocol.decode_type2(frame, motor_id=motor_id)
                        value = {"mode_state": fb.mode_state, "fault_bits": fb.fault_bits,
                                 "raw_frame": frame.record()}
                    else:
                        continue
                else:
                    continue
                _require(match is None, "Duplicate matching reply in one serial read")
                match = value
            if match is not None:
                _require(not self.parser.buffer, "Partial residual frame after matching response")
                match.update(request_started_monotonic_ns=started, received_monotonic_ns=received)
                self.emit({"kind": "version_exchange_result", "motor_id": motor_id, "step": step, **match})
                return match
        self.emit({"kind": "version_deadline", "motor_id": motor_id, "step": step,
                   "monotonic_ns": self.clock(), "deadline_monotonic_ns": deadline})
        if step == "version":
            raise VersionUnknown("No matching version reply within250ms; no fallback or later ID")
        raise TimeoutError("No fresh " + step + " response within250ms")

    def collect(self, expected_uids):
        _require(not self.collected, "Probe session cannot be reused")
        expected_uids = validate_uids(expected_uids)
        self.collected = True
        report = {"status": "ABORTED", "errors": [], "motors": [
            {"motor_id": mid, "status": "NOT_ATTEMPTED", "identity_verified": False,
             "stop_confirmed": False, "version": None} for mid in IDS], "plan": make_plan()}
        current = None
        try:
            for current in report["motors"]:
                mid = current["motor_id"]
                current["status"] = "IN_PROGRESS"
                identity = self._exchange(mid, "identity")
                _require(identity["mcu_uid_hex"] == expected_uids[mid], "Fresh motor identity mismatch")
                current["identity_verified"] = True
                current["stop_feedback"] = self._exchange(mid, "stop")
                current["stop_confirmed"] = True
                current["version"] = self._exchange(mid, "version")
                current["status"] = "VERSION_RECEIVED"
            self._boundary()
            report["status"] = "VERSION_PROBE_COMPLETE"
        except BaseException as error:
            unknown = isinstance(error, VersionUnknown)
            report["status"] = "UNKNOWN" if unknown else "ABORTED"
            report["errors"].append(type(error).__name__ + ": " + str(error))
            if current is not None and current["status"] == "IN_PROGRESS":
                current["status"] = "UNKNOWN" if unknown else "ABORTED"
        finally:
            self.poisoned = True
        report.update(write_attempts=self.write_attempts,
                      elapsed_s=(self.clock()-self.started_ns)/1e9, approved_for_runtime=False,
                      motor_enabling_available=False, motion_command_available=False,
                      settings_available=False, pure_read_only=False, boot_verified_by_tool=False)
        return report


def open_serial():
    import serial
    port = serial.Serial(port=None, baudrate=921600, bytesize=8, parity="N", stopbits=1,
                         timeout=.002, write_timeout=.02, xonxoff=False, rtscts=False,
                         dsrdtr=False, exclusive=True)
    port.dtr = port.rts = False
    port.port = "/dev/robstride-usb2can"
    try:
        port.open()
    except BaseException:
        port.close()
        raise
    return port


def _strict_object(pairs):
    result = {}
    for key, value in pairs:
        _require(key not in result, "Duplicate UID JSON key")
        result[key] = value
    return result


def _sync_directory(path):
    descriptor = os.open(path, os.O_RDONLY)
    try:
        os.fsync(descriptor)
    finally:
        os.close(descriptor)


def main(argv=None):
    parser = argparse.ArgumentParser(description=__doc__)
    parser.add_argument("--execute", action="store_true", help="Send ordinary Type4 stop and shared Type4 version query")
    parser.add_argument("--expected-uids", type=Path, required=True)
    parser.add_argument("--output", type=Path, required=True)
    args = parser.parse_args(argv)
    try:
        uid_bytes = args.expected_uids.expanduser().read_bytes()
        expected = validate_uids(json.loads(uid_bytes, object_pairs_hook=_strict_object))
        if not args.execute:
            print(json.dumps(make_plan(), indent=2))
            return 0
        original = args.output.expanduser()
        _require(not original.exists() and not original.is_symlink(), "Output directory must be new")
        output = original.resolve()
        _require(not any((p/".git").exists() or (p/".git").is_symlink() for p in (output, *output.parents))
                 and Path(__file__).resolve().parent.parent not in output.parents, "Output must be outside Git/runtime")
        output.mkdir(mode=0o700, exist_ok=False)
        _sync_directory(output.parent)
    except (OSError, ValueError) as error:
        parser.error(str(error))
    report = {"status": "ABORTED", "errors": [], "plan": make_plan(),
              "started_at_utc": datetime.now(timezone.utc).isoformat(),
              "expected_uid_file_sha256": hashlib.sha256(uid_bytes).hexdigest(),
              "source_sha256": {Path(p).name: hashlib.sha256(Path(p).read_bytes()).hexdigest()
                  for p in (__file__, codec.__file__, protocol.__file__, timing.__file__)}}
    signals, handlers, port = [], {}, None
    def check_interrupt():
        if signals:
            raise InterruptedError("signal " + str(signals[0]))
    try:
        for sig in (signal.SIGINT, signal.SIGTERM):
            handlers[sig] = signal.signal(sig, lambda number, _: signals.append(number))
        descriptor = os.open(output/"events.jsonl", os.O_WRONLY | os.O_CREAT | os.O_EXCL, 0o600)
        with os.fdopen(descriptor, "w", encoding="utf-8") as stream:
            def emit(event):
                stream.write(json.dumps({"wall_time_ns": time.time_ns(), **event}, allow_nan=False)+"\n")
                stream.flush()
                os.fsync(stream.fileno())
            emit({"kind": "version_probe_metadata", "monotonic_ns": time.monotonic_ns(), **make_plan()})
            with timing.ownership_locks():
                check_interrupt()
                port = open_serial()
                try:
                    report.update(VersionProbe(port, emit, check_interrupt=check_interrupt).collect(expected))
                finally:
                    port.close()
                    port = None
                check_interrupt()
    except BaseException as error:
        report["status"] = "ABORTED"
        report["errors"].append(type(error).__name__ + ": " + str(error))
    finally:
        if port is not None:
            try:
                port.close()
            except BaseException as error:
                report["errors"].append("Port close failed: " + repr(error))
                report["status"] = "ABORTED"
        try:
            report["signals"] = signals
            report["completed_at_utc"] = datetime.now(timezone.utc).isoformat()
            events_path = output/"events.jsonl"
            report["events_sha256"] = hashlib.sha256(events_path.read_bytes()).hexdigest() if events_path.exists() else None
            serialized = json.dumps(report, ensure_ascii=False, indent=2, allow_nan=False)+"\n"
            descriptor = os.open(output/"summary.json", os.O_WRONLY | os.O_CREAT | os.O_EXCL, 0o600)
            with os.fdopen(descriptor, "w", encoding="utf-8") as stream:
                stream.write(serialized)
                stream.flush()
                os.fsync(stream.fileno())
            _sync_directory(output)
        finally:
            for sig, handler in handlers.items():
                signal.signal(sig, handler)
    print(json.dumps({"output": str(output), "status": report["status"],
                      "write_attempts": report.get("write_attempts", 0),
                      "motor_enabling_available": False, "pure_read_only": False,
                      "approved_for_runtime": False}))
    return 0 if report["status"] == "VERSION_PROBE_COMPLETE" else 2


if __name__ == "__main__":
    raise SystemExit(main())

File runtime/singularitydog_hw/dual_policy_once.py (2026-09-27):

"""Bounded two-USB2CAN + IMU capture, then one no-output policy observation.

CAN is restricted by the existing dual pipeline to Type0 UID and Type17
position/velocity reads. The IMU reader temporarily configures its own sensor
and restores it. Inference uses a completed capture's original host timestamps;
it is deliberately post-capture and establishes no 20 ms control performance.
No RS05 enable, STOP, setting write, motion frame, or command transport exists.
"""

import argparse
import datetime
import hashlib
import json
import os
from pathlib import Path
import queue
import signal
import threading
import time

from . import dual_can_pipeline_benchmark as dual
from . import policy_observer as observer
from . import policy_observer_live as live
from . import policy_observer_replay as replay
from . import policy_shadow as shadow
from . import telemetry_snapshot as telemetry
from .angle_branch_comparison import StaticBranchComparison


FLAGS = {"motor_output_available": False, "output_allowed": False,
         "approved_for_runtime": False, "learned_target_sent": False,
         "live_50hz_verified": False, "calibration_verified": False,
         "h_measured": False, "can_allowed_types": [0, 17]}
MAX_SECONDS = 10.
MAX_IMU_ROWS = 1200


def _need(condition, message):
    if not condition:
        raise ValueError(message)


def reviewed_branch_manifest(data, boot_id, motor_power_epoch, expected_uids):
    """Reconstruct the existing static review object from a saved manifest."""
    if data is None:
        return None
    _need(motor_power_epoch != "UNVERIFIED",
          "A branch manifest needs an independently observed motor power epoch")
    _need(type(data) is dict and data.get("status") == "OPERATOR_ATTESTED_REVIEW_REQUIRED"
          and data.get("motor_output_allowed") is False
          and data.get("approved_for_runtime") is False
          and data.get("boot_id") == boot_id,
          "Branch manifest is not a matching no-output boot review")
    comparison = StaticBranchComparison(data.get("reference_snapshot"),
                                        data.get("current_snapshot"),
                                        data.get("no_turn_evidence"))
    _need(comparison.comparison() == data.get("branch_comparison"),
          "Branch manifest comparison differs from its snapshots")
    binding = comparison.validated_current_binding()
    _need(binding["boot_id"] == boot_id
          and binding["motor_power_epoch"] == motor_power_epoch
          and binding["uids_by_id"] == {str(i): expected_uids[i] for i in range(1, 13)},
          "Branch manifest UID/boot/motor-power epoch binding changed")
    return comparison


def observe_one(dual_report, events_by_bus, imu_events, calibration, mount, policy,
                torch_module, *, h_hypothesis, boot_id, motor_power_epoch,
                branch_comparison=None,
                max_age_ns=100_000_000, max_spread_ns=100_000_000,
                warmup_completed=False):
    """Pure post-capture adapter for validated Type0/17 and raw IMU events."""
    _need(type(boot_id) is str and bool(boot_id.strip()), "Missing capture boot ID")
    _need(type(motor_power_epoch) is str and bool(motor_power_epoch.strip()),
          "Missing motor power epoch label; use UNVERIFIED without a manifest")
    _need(type(h_hypothesis) is int and h_hypothesis in (0, 1),
          "Only an explicit diagnostic h=0/1 hypothesis is accepted")
    _need(type(max_age_ns) is int and 0 < max_age_ns <= 100_000_000
          and type(max_spread_ns) is int and 0 < max_spread_ns <= 100_000_000,
          "Diagnostic age/spread must be at most 100 ms")
    _need(type(dual_report) is dict
          and dual_report.get("status") == "COMPLETE_DUAL_CAN_BENCHMARK_NO_OUTPUT"
          and dual_report.get("output_allowed") is False
          and dual_report.get("producer_threads_exited") is True
          and dual_report.get("common_lock_released") is True
          and dual_report.get("errors") == [],
          "Require completed, closed, no-output two-bus capture")
    _need(type(events_by_bus) is dict and set(events_by_bus) == {"front", "rear"}
          and all(type(events_by_bus[bus]) is list for bus in events_by_bus),
          "Require both original bus event streams")
    _need(type(imu_events) is list and 0 < len(imu_events) <= MAX_IMU_ROWS,
          "Require bounded IMU source events")
    rows = shadow.validate_calibration(calibration)
    shadow.validate_imu_mount_candidate(mount)
    _need(calibration.get("approved_for_runtime") is False
          and all(row.get("approved_for_runtime") is not True for row in rows.values()),
          "Only unapproved calibration candidates are accepted")
    expected = calibration["identities"]
    seen_uids, seen_values = {}, set()
    last_finishes = []
    buffer = telemetry.TelemetrySnapshotBuffer(history_per_key=32,
        max_age_ns=max_age_ns, max_spread_ns=max_spread_ns)
    for bus, ids in dual.SCOPES.items():
        for event in events_by_bus[bus]:
            if event.get("kind") != "pipeline_reply":
                continue
            mid, parameter, cycle = (event.get(key) for key in
                                      ("motor_id", "parameter", "cycle"))
            result = event.get("result")
            _need(type(mid) is int and mid in ids and type(result) is dict
                  and event.get("ok") is True and result.get("ok") is True,
                  "Invalid dual-bus reply or motor assignment")
            if parameter == "identity":
                _need(cycle == 0 and mid not in seen_uids
                      and result.get("mcu_uid_hex") == expected[str(mid)],
                      "Fresh identity does not match calibration")
                seen_uids[mid] = result["mcu_uid_hex"]
            elif parameter in ("position", "velocity"):
                _need(mid in seen_uids and type(cycle) is int and 1 <= cycle <= 20
                      and (cycle, mid, parameter) not in seen_values,
                      "Telemetry missing identity or repeated within a cycle")
                seen_values.add((cycle, mid, parameter))
                buffer.ingest_pipeline_reply(event)
                if cycle == 20:
                    last_finishes.append(event["received_monotonic_ns"])
            else:
                raise ValueError("Unexpected CAN parameter in no-output capture")
    _need(set(seen_uids) == set(range(1, 13)) and len(seen_values) == 20*24
          and len(last_finishes) == 24,
          "Incomplete twelve-axis identity or position/velocity capture")
    previous_sequence = 0
    for event in imu_events:
        _need(type(event) is dict and event.get("kind") == "imu"
              and event.get("frame") == "sensor"
              and type(event.get("sequence")) is int
              and event["sequence"] == previous_sequence + 1,
              "IMU source sequence/frame invalid")
        previous_sequence += 1
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

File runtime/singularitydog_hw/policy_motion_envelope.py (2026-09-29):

"""Pure twelve-axis shaping and monitoring for reviewed supported trials.

All tuples use CAN ID 1..12 order, in calibrated model coordinates.  This module
does not encode frames, enable motors, select physical limits, or permit an
unsupported trial.  The caller must provide reviewed per-axis limits and map
model positions back to the current, UID-bound raw-angle branch.

Position references follow continuous, bounded-velocity/acceleration trajectories.
MIT velocity references and feedforward torque remain zero: the internal reference
velocity is bookkeeping, not a second damping target.  PD torque is an estimate
from the new command and measured state, NOT a physical motor torque cap.

request_stop() stops accepting policy targets.  Starting at the last command it
brakes each reference continuously, then decreases gains with a quintic ramp.
Completion is no later than max(v_limit/a_limit) + stop_duration_s from the last
command, plus at most one sample interval to observe it.  The caller must keep
support in place, continue fresh samples, and issue the hardware STOP at completion.
A MotionFault is latched and requires an immediate caller-managed hardware STOP;
no graceful ramp is attempted after a fault.  Recreating this object is not fault
recovery authorization.
"""

from dataclasses import dataclass
import math
from numbers import Real
from typing import Optional, Sequence, Tuple


AXIS_COUNT = 12


class MotionFault(ValueError):
    """A hard monitoring or input fault; the owner must stop hardware output."""


def _number(value, name):
    if isinstance(value, bool) or not isinstance(value, Real):
        raise MotionFault(f"{name}: finite real number required")
    try:
        converted = float(value)
    except (ValueError, OverflowError) as exc:
        raise MotionFault(f"{name}: finite real number required") from exc
    if not math.isfinite(converted):
        raise MotionFault(f"{name}: finite real number required")
    return converted


def _positive(value, name):
    value = _number(value, name)
    if value <= 0:
        raise MotionFault(f"{name}: positive value required")
    return value


def _vector(values, name):
    # The live decoder supplies exact float tuples. Validate those in C-level
    # loops while retaining the generic conversion/rejection path for every
    # other input type (including bool, int, and float subclasses).
    if (type(values) is tuple and len(values) == AXIS_COUNT and
            all(type(value) is float for value in values) and
            all(map(math.isfinite, values))):
        return values
    if isinstance(values, (str, bytes)):
        raise MotionFault(f"{name}: twelve numeric values required")
    try:
        result = tuple(_number(value, name) for value in values)
    except TypeError as exc:
        raise MotionFault(f"{name}: twelve numeric values required") from exc
    if len(result) != AXIS_COUNT:
        raise MotionFault(f"{name}: exactly twelve axes required")
    return result


@dataclass(frozen=True)
class AxisLimits:
    lower_rad: float
    upper_rad: float
    kp: float
    kd: float
    max_command_velocity_rad_s: float
    max_command_acceleration_rad_s2: float
    max_tracking_error_rad: float
    max_measured_velocity_rad_s: float
    max_measured_torque_nm: float
    max_temperature_c: float
    max_estimated_pd_torque_nm: float
    max_displacement_from_start_rad: float

    def __post_init__(self):
        for name in self.__dataclass_fields__:
            value = _number(getattr(self, name), name)
            object.__setattr__(self, name, value)
        if self.lower_rad >= self.upper_rad:
            raise MotionFault("AxisLimits: lower_rad must be below upper_rad")
        if self.kp < 0 or self.kd < 0:
            raise MotionFault("AxisLimits: gains must be nonnegative")
        for name in self.__dataclass_fields__:
            if name not in ("lower_rad", "upper_rad", "kp", "kd"):
                _positive(getattr(self, name), name)


@dataclass(frozen=True)
class MotionSample:
    q_model_rad: Tuple[float, ...]
    velocity_rad_s: Tuple[float, ...]
    torque_nm: Tuple[float, ...]
    temperature_c: Tuple[float, ...]
    monotonic_s: float

    def __post_init__(self):
        for name in ("q_model_rad", "velocity_rad_s", "torque_nm", "temperature_c"):
            object.__setattr__(self, name, _vector(getattr(self, name), name))
        stamp = _number(self.monotonic_s, "sample monotonic_s")
        if stamp < 0:
            raise MotionFault("sample monotonic_s must be nonnegative")
        object.__setattr__(self, "monotonic_s", stamp)


@dataclass(frozen=True)
class MotionCommand:
    q_model_rad: Tuple[float, ...]
    kp: Tuple[float, ...]
    kd: Tuple[float, ...]
    velocity_reference_rad_s: Tuple[float, ...]
    feedforward_torque_nm: Tuple[float, ...]
    command_velocity_rad_s: Tuple[float, ...]
    tracking_error_rad: Tuple[float, ...]
    estimated_pd_torque_nm: Tuple[float, ...]
    gain_scale: float
    phase: str
    stop_stage: Optional[str]
    monotonic_s: float


def _quintic_fraction(value):
    # Bounding elapsed fractions is not clamping an invalid policy target.
    if value <= 0:
        return 0.
    if value >= 1:
        return 1.
    # Near one, floating-point cancellation can produce 1 + a few ulps and
    # make a stopping gain negative. Bound this dimensionless ramp only;
    # policy targets and measured limits continue to reject invalid values.
    return min(1., max(0., value ** 3 * (10. + value * (-15. + 6. * value))))
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

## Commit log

2026-09-09 Add robot design and learning skills with measured loop history
    [synthetic_robot.urdf]
2026-09-09 Add selected robot recordings and CAD view to development history
2026-09-09 Publish L11 forward 40 cm/s results and six-direction comparison
2026-09-10 Document L15 evaluation and next hardware mounting specifications
2026-09-11 Show one action cycle with grayscale end frames in trial 25 preview
2026-09-11 Label 14-second motion preview in cyan and preserve color on end frames
2026-09-12 Publish Trial 27 results and dense yellow STL print plates
    [A1_FL_hip_mm.stl, A2_FL_thigh_collar_mm.stl, A3_FL_thigh_mm.stl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]
2026-09-15 Publish revised equipment deck and lower carbon pole mounting kit
    Document the Jetson fastener reliefs and hole checks, provide the shared K1 Max deck and eight lower-pole clamp parts, and add assembly diagrams, hardware dimensions, and explicit verification limits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
    [B17_d20_long_-1_-1_-1_lower_mm.stl, B18_d20_long_-1_-1_-1_upper_mm.stl, B19_d20_long_-1_1_-1_lower_mm.stl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]
2026-09-17 Publish deployment roadmap, milestone history, BOM and current STL catalog
    [B01_FL_hip_front_collar_reinforced_r1_mm.stl, B02_FL_rear_base_mount_crosslink_r2_mm.stl, B03_FR_hip_front_collar_reinforced_r1_mm.stl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]
2026-09-17 Feature CAD, Astra development, deployment status and CERN hardware licence
2026-09-18 Replace README hero with verified yellow CAD assembly
2026-09-21 Publish September 21 hardware results and commissioning runtime
    Document supported right-front motion and verified stops, preserve tracking and deployment limitations, and add the next-session plan. Update hardware selections and publish the offline-tested commis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
2026-09-24 Publish September 22-24 hardware results and integrated timing measurements
    Summarize four-leg commissioning, dual CAN acquisition, calibration candidates, and the remaining deployment gates. Record integrated STOP-proxy latency of 37.780ms median and 39.089ms maximum withou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
    Publish the reviewed runtime improvements, selected evidence and tests; refresh README, BOM and the explicit release manifest. Validation: 705 runtime tests, 32 publication/tool tests, publication sc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
    [motor-firmware-inventory-20260922.json]
2026-09-26 Preserve September 26 Jetson measurements and ID7 photo comparison
    [id7-position-velocity-20260926.csv]
2026-09-28 Prepare supported policy retry and record September 28 diagnostics
    Add native control and calibration workflows, final-input timing evidence, bounded supported output, and the morning retry kit design. Record the aborted hardware attempt without claiming learned output, improve STOP confirmation and failure timing, and add opt-in worker CPU affinity with restoration.
    [angle_calibration_audit.py, event_snapshot.py, imu.py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]
2026-09-29 Record supported policy results and harden preload preparation
    Preserve September 29 supported output results, Jetson runtime/test programs,
    and the exact r64 source provenance. Update README and the remaining-work
    checklist through the September 30 handoff.
    Validate the finite preload path, captured joint data and encoder branches;
    remove host-scheduling dependence from semantic regression tests. The 0.25mm
    preload remains file-only: active-runner integration, fault/STOP integration
    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
2026-10-02 Prepare robot trials with angle branching, spoken cues and bounded waits
    Record October 2 trial results and remaining work in README, daily documentation and public evidence. Add supported trial preparation, mixture analysis and device-free regression tests.
    Preserve the latest ID10 enable-reply failure and unconfirmed STOP status. New voltage-wait hardware requalification, load transfer, standing and walking remain pending.
    [diagnostic_angle_branch.py, human_supported_hold.py]
2026-10-02 Harden robot stop evidence and prepare formal walking trials
    Preserve unresolved reply ambiguity across repeated STOP, validate per-bus ground stop evidence, and shorten CAN/IMU acquisition joins with bounded native readiness waits. Fix terminal restoration and original receipt validation, retain pinned fast execution settings in unapproved formal profiles, and add a file-only reply failure analyzer.
    Validation: runtime 2619 passed/4 skipped, tools 490 passed/13 skipped; three saved-model and native socket integration cases passed. Document remaining hardware gates and the October 5-11 walking plan without claiming new hardware validation.
2026-10-05 Improve robot validation timing and calibration diagnostics
    Optimize acquisition and voltage joins, strengthen STOP and calibration evidence,
    and add traced joint, velocity, optical-motion and spoken level-reversal tools.
    Record the October 5 scoped 20ms results and remaining steps toward walking.
    Validation: runtime 2740 passed / 4 skipped; tools 696 passed / 12 skipped.
    Fix two test-only clock fixtures; production deadlines remain unchanged.
    Private raw logs and device identities are excluded from this commit.
    [angle_calibration_audit.py, imu_calibration.py, imu_calibration_review.py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]
2026-10-06 Optimize robot diagnostics and record Oct 6 results
    Add C snapshot copying, C++ target/FK reuse, bounded wait and ownership diagnostics, and calibration/camera analysis tools with tests.
    Record two disabled R49 measurements with 500 steady cycles each below 20 ms at a 900 us request gap. Retain startup overruns, start jitter, failed runs and unqualified active output. Summarize remaining calibration, Type1, load, standing and walking work; defer the supported Type1 trials to the user-requested next session.
    Include source, tests and anonymized summaries. Raw Jetson logs and operator observations remain in the private Mac backup.
    Validation: runtime 3233 cases (4 skips), tools 937 cases (1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
    [active_output_timer_slack.py, imu_accel_input_hypothesis.py, native_active_transport.py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]
